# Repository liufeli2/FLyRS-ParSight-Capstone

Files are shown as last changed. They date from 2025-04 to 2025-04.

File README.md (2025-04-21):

# ParSight - FLyRS [ROB498 Capstone]

This repository showcases our work for ROB498, the Robotics Capstone Design course of Engineering Science (Robotics Engineering) at the University of Toronto. Our team is building a fully functional Micro Aerial Vehicle (MAV) that tackles the Sense-Plan-Act paradigm, alongside complete hardware assembly. From brainstorming and prototyping to testing and integration, this project holistically combines our engineering skills to create a cohesive hardware-software system addressing a real-world robotics challenge. In this repository, you'll find design documentation, code, performance evaluations, and final reports—a hands-on technical journey that brings together everything we've learned.

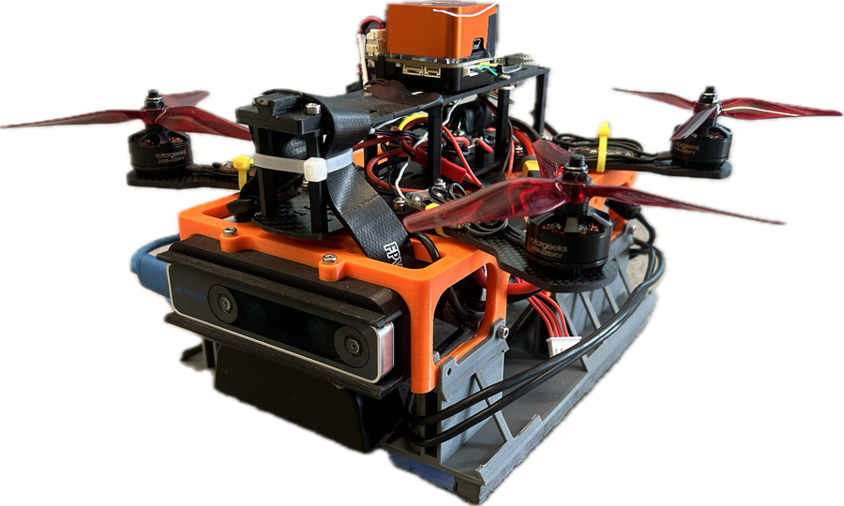
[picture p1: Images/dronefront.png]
ParSight


## Abstract

Golf is an increasingly popular pastime among seniors, offering physical and mental benefits. However, many older golfers report difficulty tracking and locating the ball visually after hitting a shot due to age-related vision decline. Existing ball tracking tools focus on broadcasting graphics and post-game analysis, with no current solutions providing real-time visibility during game play.

ParSight is an autonomous drone-based, real-time golf ball tracking system designed to enhance visibility for senior golfers. The system maintains visual contact with the ball throughout its flight, flies stably, and makes fast, accurate, and robust tracking decisions in real time. To enable fast visual detection using its onboard RGB camera, we use a red golf ball and an HSV-based red filter to enhance red tones while suppressing blue and green channels, followed by added Gaussian blur to reduce image noise. The system uses OpenCV contour detection to identify red regions, scoring them based on size and roundness to select the most likely golf ball candidate. From the selected contour, the center point is extracted and used for tracking, which is performed through Image Based Visual Servoing, where pixel error, the offset between the ball’s position on the screen and the image center, is transformed into a real-world pose correction. ParSight uses a PD controller to determine the drone’s movement, enabling smooth, responsive flight without overshooting. Once the system detects the ball, ParSight autonomously takes off, ascends to tracking height, and locks onto its target ball. When the ball is launched (via a catapult proxy), the drone tracks its flight through rapid acceleration, airtime, bounces, and eventual rolling to a stop. It continues to hover over the ball’s final position, providing constant visual feedback to aid users in locating it.

<p align="left">
  MY580 Demo
  Rviz Demo
</p>

ParSight achieved a detection accuracy of 95% with only a 3% false positive rate. Although processing latency was just 30 ms, the total system reaction time was approximately 350 ms due to hardware constraints such as camera frame rate and resolution. As a result, the maximum positional error reached 75.51 cm, though the system could still reliably recover and reacquire the ball. These results demonstrated that ParSight met the objectives of the MVP: a working prototype that detects and tracks a golf ball quickly and fairly robustly in real-testing conditions.

The design and implementation of ParSight allowed the team to apply concepts from across their undergraduate journey while navigating the real-world challenges of robotics engineering, such as debugging hardware, tuning control systems, integrating computer vision pipelines, recovering from drone crashes, and collaborating effectively as a team throughout the process.

## Team

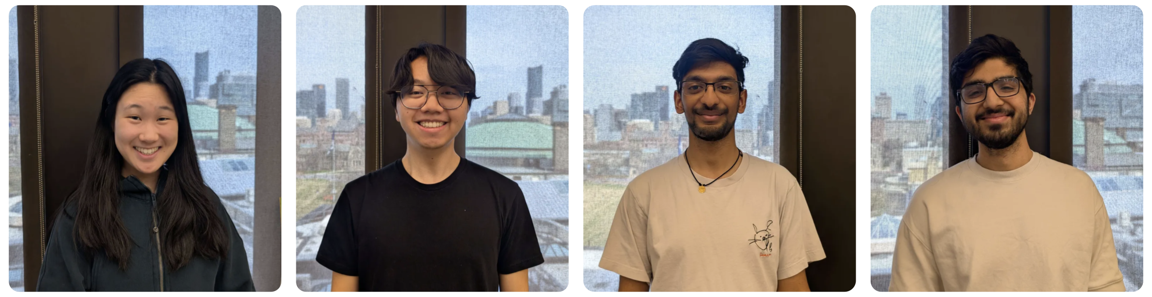
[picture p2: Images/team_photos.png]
Team Photo


We are the FLyRS. From left to right, Felicia Liu, Luke Yang, Rohan Batchu, and Sid Khanna.

## Deliverables

### [Project Proposal](CourseDeliverables/FLyRS_ParSight_Project_Proposal.pdf)
This deliverable served as the foundational step in our project, where we defined the problem, scoped the design, and outlined our approach for solving the golf ball tracking challenge using an unmanned micro aerial vehicle (MAV). The goal was to clearly communicate the design challenge, the motivation behind it, and the proposed solution. We provided a detailed explanation of the design objectives, the critical constraints, and the technical strategy we intend to pursue. This document also sets the stage for the subsequent phases of the project, ensuring alignment with the project's goals and providing a clear framework for evaluation and validation of the final system.

### [Pitch Video](https://youtu.be/EOtyIKrfoxo?si=AKbyNcsjM8_lEWE2)
This video showcases our golf ball tracking drone prototype, demonstrating how it uses computer vision and deep learning to track and locate golf balls in real time. We highlight the key technical features, challenges faced, and how our solution benefits senior golfers and those with mobility issues. The video emphasizes the prototype’s functionality and its potential to improve the golfing experience by providing an intuitive visual aid.

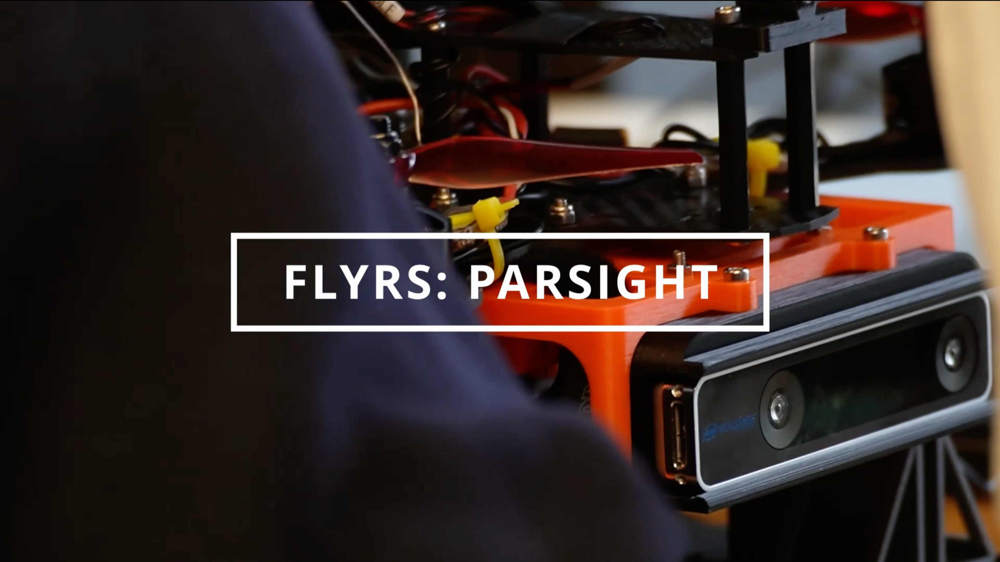
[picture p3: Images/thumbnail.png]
YouTube Video


### [Demo Presentation](CourseDeliverables/FLyRS_ParSight_Demo_Presentation.pdf)
This presentation served as the culmination of our design efforts, where we demonstrated a working prototype that addressed the core problem defined in our proposal. The goal was to showcase the key technical features of our system, explain the design process we followed, and justify the major decisions and trade-offs we made along the way. We aimed to convey the value of our solution, highlight the functionality achieved, and provide a clear understanding of how the prototype fulfilled our main objectives.

### [Final Report](CourseDeliverables/FLyRS_ParSight_Final_Report.pdf)
This report serves as the culmination of our design efforts, where we present a comprehensive overview of our project and the results achieved. The goal is to summarize the design process, highlight key decisions and trade-offs, and demonstrate how the final prototype meets the objectives outlined in our proposal. We aim to clearly communicate the value of our solution, the technical features developed, and the challenges faced throughout the process. Through this report, we provide a detailed understxwanding of the design, its functionality, and how it addresses the core problem.

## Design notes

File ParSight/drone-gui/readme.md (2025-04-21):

# Flight Procedure

## Pre-Flight Checks
- Before launching, complete the following safety and setup steps:
- Ensure all wires are clear, the net is pulled, and the test area is secure.
- Confirm time synchronization between onboard and ground systems.
- Verify vision pose matches local position in RViz.
- Ensure Vicon data is streaming correctly and matches expectations.

## Flight Process
- Launch Camera Node and Detection Node.
- Wait for successful detection of the golf ball in the scene.
- Once confirmed, unkill, arm, and switch to Offboard mode.
- Launch ParSight node to begin visual tracking.
- Wait until drone reaches stable flying height, then begin the test.
- Trigger the catapult once the drone begins active tracking.
- The drone will hover over the ball once it detects the ball has come to rest.
- Land the drone and kill to complete the demo.

## General Troubleshooting
If issues arise during setup or flight:
- Relaunch the MAVROS node.
- Replug drone hardware connections.
- Reboot the Cube flight controller.
- Swap in a fully charged battery.
- Recalibrate sensors if alignment issues persist.

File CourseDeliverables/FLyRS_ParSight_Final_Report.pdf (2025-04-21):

### ROB498: Robotics Capstone Design Team Final Report

# ParSight

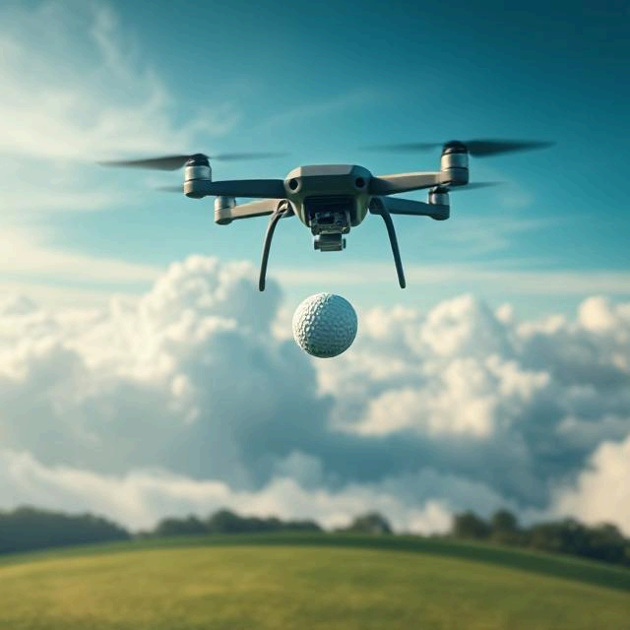
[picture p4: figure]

### Team #1: FLyRS

Felicia Liu (1006950042)
Luke Yang (1006959258)
Rohan Batchu (1006997181)
Siddharth Khanna (1006773341)

## Abstract

Golf is an increasingly popular pastime among seniors, offering physical and mental benefits. However, many older golfers report difficulty tracking and locating the ball visually after hitting a shot due to age-related vision decline. Existing ball tracking tools focus on broadcasting graphics and post-game analysis, with no current solutions providing real-time visibility during game play.

ParSight is an autonomous drone-based, real-time golf ball tracking system designed to enhance visibility for senior golfers. The system maintains visual contact with the ball throughout its flight, flies stably, and makes fast, accurate, and robust tracking decisions in real time. To enable fast visual detection using its onboard RGB camera, we use a red golf ball and an HSV-based red filter to enhance red tones while suppressing blue and green channels, followed by added Gaussian blur to reduce image noise. The system uses OpenCV contour detection to identify red regions, scoring them based on size and roundness to select the most likely golf ball candidate. From the selected contour, the center point is extracted and used for tracking, which is performed through Image Based Visual Servoing, where pixel error, the offset between the ball’s position on the screen and the image center, is transformed into a real-world pose correction. ParSight uses a PD controller to determine the drone’s movement, enabling smooth, responsive flight without overshooting. Once the system detects the ball, ParSight autonomously takes off, ascends to tracking height, and locks onto its target ball. When the ball is launched (via a catapult proxy), the drone tracks its flight through rapid acceleration, airtime, bounces, and eventual rolling to a stop. It continues to hover over the ball’s final position, providing constant visual feedback to aid users in locating it.

ParSight achieved a detection accuracy of 95% with only a 3% false positive rate. Although processing latency was just 30 ms, the total system reaction time was approximately 350 ms due to hardware constraints such as camera frame rate and resolution. As a result, the maximum positional error reached 75.51 cm, though the system could still reliably recover and reacquire the ball. These results demonstrated that ParSight met the objectives of the MVP: a working prototype that detects and tracks a golf ball quickly and fairly robustly in real-testing conditions.

The design and implementation of ParSight allowed the team to apply concepts from across their undergraduate journey while navigating the real-world challenges of robotics engineering, such as debugging hardware, tuning control systems, integrating computer vision pipelines, recovering from drone crashes, and collaborating effectively as a team throughout the process.

All source code, design files, and documentation related to this project can be found in our GitHub repository: https://github.com/liufeli2/FLyRS-ParSight-Capstone.

## Table of Contents

## Design Overview

To help senior golfers with declining vision, we present an autonomous drone-based real-time golf-ball tracking system. Using computer vision and control algorithms, ParSight can track and fly with a golf ball from the tee to its landing location, serving as a larger visual marker. Testing results demonstrate that our prototype reliably tracks a golf ball launched from a mini-catapult, meeting key performance metrics we have defined for a minimum viable product (MVP). With improved hardware, we are confident in our ability to extend this system to track full-speed outdoor shots.

With this solution in mind, we will now explain the significance of the problem it addresses. Golf has become an increasingly popular pastime among seniors, with participation among those aged 65 and older rising by 64% in the past decade and those 50 and above making up 43% of U.S. golfers in 2024 [1]. (https://www.zotero.org/google-docs/?armMck) With the correlation between age and vision decline [2], (https://www.zotero.org/google-docs/?XSq5nM) senior golfers have expressed increasing challenges in tracking and locating the ball after hitting a shot [3][4]. (https://www.zotero.org/google-docs/?Od1ESU) Existing solutions primarily are for performance tracking, video enhancement, or post-game analysis:

- Augmented Reality (AR) Golf Shot Tracers: Enhances video recordings or live broadcasts by overlaying ball trajectories using AR, helping viewers follow the shot more easily. However, these systems are designed for post-processing or broadcast purposes and do not provide real-time tracking for the golfer on the course [5][6]. (https://www.zotero.org/google-docs/?kQMq7y)
- Manually Piloted Drones: A dedicated pilot manually flies a drone to track shots, providing viewers with dynamic camera angles [7][8]. (https://www.zotero.org/google-docs/?h784Wf) However, this setup is unrealistic for everyday golfing, as it requires constant human involvement and disrupts the natural flow of play.
- Follow-Me Drones: Drones equipped with the ability to autonomously track a subject for various sports applications such as skateboarding or biking [9]. (https://www.zotero.org/google-docs/?3dN5NJ) These general solutions do not consider the following small objects travelling in the air at high speeds, such as a golf ball.

By considering the limitations of existing solutions, it is evident there is a gap in the market for a drone that autonomously tracks a golf ball in real-time and helps senior golfers locate their shots.

In developing our solution, the design process was guided by three core values: autonomy, safety, and creativity. First, restoring autonomy to senior golfers is a key element of our value proposition. By offering a larger visual marker to track the ball, our system helps restore the golfing experience seniors used to have without fundamentally changing how the game is played. Second, safety has been a central consideration in our engineering decisions, with an incremental approach that starts with basic implementations and tests and gradually progresses to more integrated evaluations. Finally, creativity shaped our ability to apply both past course knowledge and newly acquired skills in novel ways that have not been explored in this context before. Concerning our design process, the responsibilities and contributions of our team were also divided as follows:

- Felicia: Coded the red detection filter and entire tracking pipeline. Designed and initiated the incremental testing plan, beginning with testing and tuning the detection and tracking systems on a computer before porting them to the drone. Designed the landing gear in CAD.
- Luke: Set up development environment, deployment pipeline, and package management. Created development tools such as graphic user interfaces for easy debugging and automated deployment scripts. Performed data collection and analysis concerning evaluation metrics.
- Rohan: Established the RGB camera vision system. Developed the entire requirements model by researching testing metrics and ideal numbers for the final and MVP design.
- Sid: Developed the YOLO segmentation component before pivoting to the red detection filter, cleaning online datasets, collecting training data, and fine-tuning hyperparameters.

## Background and Related Work

The following section covers all the relevant software frameworks we have used in our final design, explaining how they work, their general use case, and why we have chosen them for our final design solution. The three main components are: HSV colour detection, Image-Based Visual Servoing (IBVS) and Proportional Derivative (PD) Control.

HSV Colour Detection
Colour detection algorithms identify pixels in an image that match a specific colour or colour range [10]. (https://www.zotero.org/google-docs/?RLigol) The HSV colour space is often preferred over RGB because it separates hue, saturation, and value, making colour detection more robust and reliable [11]. (https://www.zotero.org/google-docs/?w3M9QA) The algorithm is particularly well suited in industries like manufacturing, automotive, and food processing where distinguishing between objects based on colour is essential. For example, identifying similar-looking products, inspecting colored adhesives or baked goods, and detecting naturally colourful materials [12]. (https://www.zotero.org/google-docs/?fKOsAu) We selected HSV colour detection for our design because golf balls are typically monochromatic, aligning well with the algorithm’s strengths. Additionally, HSV-based detection is computationally efficient, which is critical for tracking fast-moving objects like a golf ball.

Image-Based Visual Servoing
Image-Based Visual Servoing (IBVS) is a common practice in robotics that utilizes computer vision to provide a closed-loop position control for a robot end-effector. Specifically for mobile robotics, the goal is to control the vehicle’s pose with respect to some landmark [13]. (https://www.zotero.org/google-docs/?xmze43) Within industry, visual servoing has been used for bin picking, packaging, and sorting tasks in a controlled environment [14]. (https://www.zotero.org/google-docs/?c6X8v4) We chose IBVS for our design because it aligns well with our design problem. Specifically, we control the drone’s pose relative to the golf ball, which acts as a visual landmark in the camera frame. Compared to dynamics-based control systems, IBVS also offers a simpler implementation that can take advantage of the drone’s existing integrated setpoint control system.

Proportional Derivative Control
Proportional Derivative (PD) control is a simplified form of the widely used Proportional Integral Derivative (PID) control algorithm. By measuring input data from sensors, the difference between the actual value and the desired setpoint of a system can be calculated and used to adjust the outputs to correct the error [15]. (https://www.zotero.org/google-docs/?UOlTbM) Industry use cases include temperature, power electronics, automatic machines, and automobile control [16]. (https://www.zotero.org/google-docs/?r8EAlR) We chose to use PD control when determining the desired setpoint from the IBVS control output because of its reputable industry performance. We excluded the integral component to prioritize rapid response and effective damping of oscillations, as steady-state accuracy was not a primary concern for our application.

## Design Objectives and Solution Details

In the submitted proposal and during the early stages of the project, the requirements were not as well defined; we have since fleshed out the requirements model through further development. The new requirements are better defined to enable benchmarking and testing of our prototype. In addition to this, feedback from course instructors informed our new scope, which constrained our primary functions to tracking the golf ball, hovering over the golf ball, and being easy to set up and use. One of the goals we removed was the obstacle avoidance due to the limited time frame for prototyping, as well as the limited hardware capabilities of the drone. Some functions were also altered and added to better describe the system’s interfaces and necessary capabilities that were realized during development. Additionally, performance requirements were developed and altered as well as including more finalized specifications.

Our project scope now has 3 main objectives with the following requirement codes:

- MLR-001: Tracking the golf ball from tee-off to rest
- MLR-002: Become a visual marker for the ball at rest
- MLR-003: Ensuring easy setup and use of the drone

These objectives are further broken down into system-level requirements (SLRs) and subsystem requirements, with the following system and subsystems and their codes:

- SLR - System Level Requirements
- IMG - Sensing and Perception
- OBD - Image Processing and Ball Detection
- FLC - Tracking and Path Planning

ParSight employs a requirement classification of three types to use as a framework for aligning design decisions with system performance and operational constraints. The category types are Functional (F), Performance (P), and Constraint (C). The requirement codes follow the syntax: <System>-<Category Type>-<Number>.

As development continued, we found that we were working in three primary areas of imaging, object detection, and actuation. As such, these 3 areas were made into subsystems (IMG, OBD, FLC) that interact with each other and other hardware onboard to create an effective solution as seen in Figure 1. The Localization system is the RealSense/Vicon system that provides real-world position data to send setpoints to the flight controller.

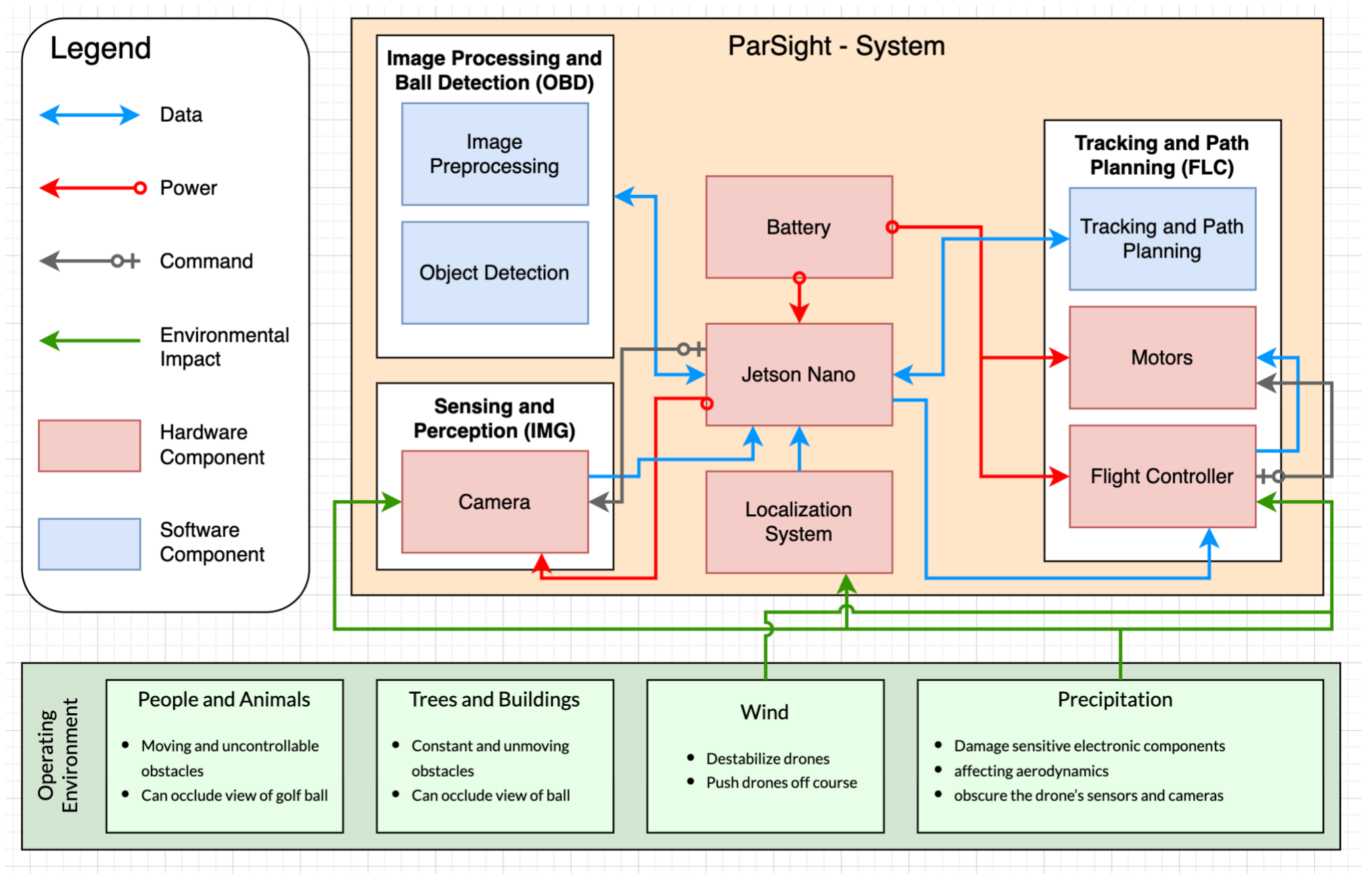
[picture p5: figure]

Figure 1. System Block Diagram showing the connections and interfaces between subsystems, the system,system hardware, and the environment.

Table 1. System Level Requirements(SLRs).
Code | Requirement | Explanation | Parent Req
SLR-P-001 | The processing latency from image to motor commands shall be less than 100 ms | The software pipeline from perception to planning must occur in less than 100ms to track a golf ball with 1 the current hardware specifications | MLR-001
SLR-P-002 | The drone shall be ready to use in under 10 minutes | To reduce technical issues and account for the varying technical skills of users, ease of use is necessary | MLR-003
SLR-F-001 | The drone shall maintain a view of and track the ball throughout flight | To track the golf ball effectively, the camera must have the golf ball in frame at all times | MLR-001
SLR-F-002 | The drone shall have a safe and stable flight when tracking the ball | Drone stability provides smoother transitions for planning and will require less image processing | MLR-001
SLR-F-003 | The drone shall have all the computation onboard | Due to the high possible speed of the golf ball, it is not viable to have a delay in receiving and sending data to a remote computer | MLR-001
SLR-F-004 | The drone shall detect the ball’s position from overhead | Since the ball starts on the ground, tracking from overhead will provide the best possible view of the ball throughout flight | MLR-001
SLR-F-005 | All drone power shall be sourced from the onboard battery | The far distance travelled by the golf ball makes a wired drone unviable | MLR-001
SLR-F-006 | The drone shall maintain a distance such that it will have minimal impact on the golf ball's trajectory | A goal of the project is to minimize the effect of the prototype on the sport of golfing, therefore, the drone must be far enough away such that the lift generated by the drone has minimal effect on the golf ball | MLR-001
SLR-F-007 | The drone shall hover over the golf ball at rest | To provide a larger visual marker for the golf ball location after a swing | MLR-002

Table 2. Subsystem Level Requirements.
Code | Requirement | Explanation | Parent Req
SENSING AND PERCEPTION REQUIREMENTS
IMG-C-001 | The camera shall weigh less than 500 grams | For the drone to be able to fly and react to control inputs, the drone cannot have too much added weight | SLR-F-002
IMG-P-001 | The camera shall provide images at least 20 Hz to the Jetson Nano | For effective tracking, based on the calculations, we require 20 Hz to capture ball motion off of tee-off | SLR-P-001
IMG-P-002 | The camera shall send images with a resolution of at least 480p | Image quality determines the ability of the object detection algorithm to find the ball in the image. A higher quality is generally better, but to find the features in the testing environment, 480p should be enough, as the detection is at a lower distance and fewer overall features [17] (https://www.zotero.org/google-docs/?qsXp1P) | SLR-F-001
IMG-F-001 | The camera shall be securely attached to the drone, facing the ground throughout flight | If the camera is not securely attached, the image and information gathered will not be effective for tracking the golf ball at all times | SLR-F-004
IMG-F-002 | The camera shall operate on power provided by the Jetson Nano | The Jetson provides power for all external devices and sensors, and as such, must be able to run on the provided power | SLR-F-003
IMG-F-003 | The camera shall provide imaging data directly to the Jetson Nano through onboard connections | The Jetson is the onboard computer, and to achieve the objectives, it must receive images from the data | SLR-F-003

1 Based on a camera FOV of 60°, estimated ball speed of 10m/s and a flight height of 2.3m, the distance the ball could travel before being lost from the frame is 1.328m which the ball travels in about 0.1328s. This requires that the pipeline speed be capable of detecting and reacting to this at a rate of at least 7.5 Hz for at least one detection.

IMG-F-004 The Jetson Nano shall provide imaging data to any required programs

The drone and all controls are being run through ROS2, and as such, if the pipeline requires multiple scripts, the images may need to be available in all files when being run all at once

SLR-F-003

IMAGE PROCESSING AND OBJECT DETECTION REQUIREMENTS
OBD-P-001 | The object detection algorithm shall operate at a frequency of at least 20 Hz | For effective tracking and based on the estimated ball speed of the MVP, the minimum required frequency was decided | SLR-P-001
OBD-P-002 | The object detection algorithm shall have a detection true positive rate of at least 90% | Effective tracking requires high recall, so when there are golf balls in the frame, the algorithm can pick out the golf ball and can identify when there is no ball in frame [18] (https://www.zotero.org/google-docs/?XkSWza) | SLR-F-001, SLR-F-002
OBD-P-003 | The object detection algorithm shall have a False Positive Rate of less than 5% | When detecting the golf ball, detecting other objects in the image background would make tracking unviable [19] (https://www.zotero.org/google-docs/?5TV8Uo) | SLR-F-001, SLR-F-002
OBD-P-004 | The object detection algorithm shall have a true positive rate of at least 85% in bright, normal, and low-light conditions | Golf can be played in all sorts of lighting conditions, so ensuring that the performance in varying environments is essential | SLR-F-001, SLR-F-002
OBD-F-001 | The object detection algorithm shall receive imaging data from the imaging system | The object detection algorithm requires images to identify and locate the golf ball | SLR-F-003
OBD-F-002 | The object detection algorithm shall segment the golf ball out of the received image | To achieve project objectives, the object detection algorithm is required to identify and locate golf balls in the image | SLR-F-001

TRACKING AND PATH PLANNING REQUIREMENTS
FLC-P-001 | Using the object detection output, the flight control shall determine drone motion within 20ms | Tracking the estimated ball position in the image and determining the next drone position needs to be done within latency to ensure the ball stays in frame | SLR-P-001
FLC-P-002 | The flight control shall maintain a distance of at most 20 cm from the ball's resting position | The goal of the project is to provide a better location of the ball's final position for the elderly and provide a larger target | SLR-F-007
FLC-P-003 | The flight control shall move with the ball within 150 ms of motion | To reduce latency and ensure that the golf ball is within the camera frame | SLR-F-001
FLC-P-004 | The flight control shall move such that the gold ball is within 10 pixels of the center of the image | To ensure tracking precision throughout flight, a maximum image frame pixel distance must be maintained | SLR-F-004
FLC-P-005 | The drone shall maintain a height of 2.3m above the ball to limit alteration of the golf ball trajectory | To minimize the effects of wind on the trajectory of the ball, a height of 2.3m was chosen to balance Vicon performance and lift force | SLR-F-006
FLC-F-001 | The flight control shall stay within the boundaries of the golf course | To ensure safety for others and the drone, it should remain within a specified region (ie. golf course) | SLR-F-002
FLP-F-002 | The flight control shall have a max speed equal to or greater than the golf ball speed | If the drone is slower than the ball, tracking will not be effective | SLR-F-001, SLR-F-002
FLC-F-003 | The flight controller shall control the drone motors to achieve the motion specified by the FLC | Conversion between the image frame setpoint and the actual drone motion is essential for tracking | SLR-F-001, SLR-F-002
FLC-F-004 | The flight controller shall land the drone if the battery is at 10% or less | This allows for drone safety to be maintained and allows for a controllable landing sequence that will not damage the environment | SLR-F-005

## Design Prototype Overview

This section outlines the implementation of ParSight, including the design and final functionality of the prototype developed. We describe the system architecture and the plan-sense-act paradigm used, including both the hardware and software components that enable our real-time golf ball tracking. We also explain the prototype’s core mechanisms for ball detection, tracking, and flight control to illustrate how the system operates end-to-end. Finally, we discuss the extent to which the current prototype meets the project’s primary objectives, along with the key considerations and modifications needed to scale ParSight for real-world deployment.

Sense-Plan-Act Robotics Paradigm
ParSight follows the Sense-Plan-Act model, a foundational paradigm in robotics that structures a robot's behaviour around three key functions: sensing the environment, planning a response, and acting upon that plan. This model provides a clear and modular way to break down the operations of ParSight’s autonomous golf ball tracking system, helping us understand how each hardware component contributes and integrates into the overall functionality of the system at a high level.

Sensors (Input)
The primary sensor used in ParSight is a downward-facing RGB camera that continuously captures a live video feed of the environment beneath the drone, where we expect to see the golf ball. We selected the NexiGo N660 USB webcam, a practical solution for our vision-based tracking needs [20]. (https://www.zotero.org/google-docs/?QquqQS) This camera can capture video at 30 frames per second, which is suitable for our proof-of-concept tracking tasks. It features a wide-angle 60° field of view, allowing us to observe a broad portion of the scene and track the golf ball effectively from the air. The 1080p Full HD resolution (1920x1080) provides more detail than strictly necessary, but the extra resolution offers flexibility, allowing us to downsample frames to reduce processing load as needed. Its USB-A connectivity simplified hardware integration, as our Jetson experienced issues with the CSI connection port. We mounted the NexiGo camera in a downward-facing orientation, fixed on the drone to ensure that its view was aligned with the drone’s local frame of reference. Once visual input is captured, image processing techniques are used to isolate the location of the red golf ball within the frame, informing the planning system on how the drone should respond.

Figure 2. Sensing Hardware: NexiGo N660 webcam.

Planners (Onboard Computation)
The onboard planning computation is handled by an NVIDIA Jetson Nano, a compact embedded computer with a quad-core ARM Cortex-A57 CPU and a 128-core Maxwell GPU capable of 0.5 TFLOPs (FP16) provided by the course instructors. This processing unit runs the Robot Operating System 2 (ROS2), which manages communication between sensing, planning, and actuation components in a modular and distributed manner. During planning, ParSight processes the image coordinate data to calculate the pixel offset between the detected golf ball and the center of the frame. This offset serves as the input to an Image-Based Visual Servoing (IBVS) algorithm, which determines the directional correction needed to maintain visual alignment. We designed our own Proportional-Derivative (PD) controller external to the built-in Orange Cube + Flight Controller in order to dynamically impose position-based control, which computes the appropriate control signals based on this error, balancing responsiveness with stability. These control outputs are subsequently passed to the actuation system to update the drone’s position in real time.

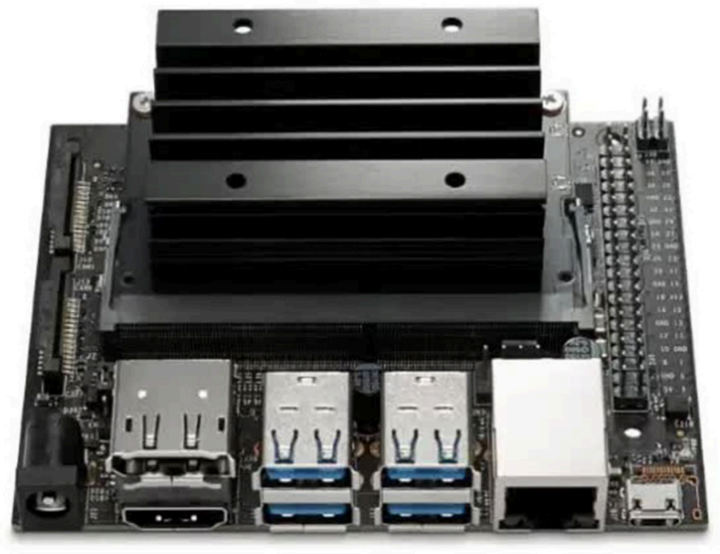
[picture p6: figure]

Figure 3. Planning Hardware: Jetson Nano (IBVS and PD control).

Actuators (Output)
Once a corrective plan is generated, the system translates it into updated flight setpoints that define the drone’s desired position in real time. These setpoints are published through ROS2 on the Jetson Nano and transmitted to the Orange Cube+ flight controller, which interprets them and initiates the appropriate motor commands. The flight controller adjusts the drone’s motion by regulating the Electronic Speed Controllers (ESCs), which in turn drive the brushless motors to produce the necessary thrust and orientation adjustments. ParSight is built on the Minion Mini H-Quad racing drone platform, equipped with 5” three-blade propellers, Spedix ES30 HV30A ESCs, and Rotorgeeks 7075 Series 2206 2350KV brushless motors. The Orange Cube+ flight controller, featuring a 32-bit ARM Cortex M7 processor and integrated IMUs, ensures precise and responsive navigation. This tightly integrated actuation system enables fast, stable flight, allowing ParSight to follow the golf ball’s movement and maintain visual lock throughout its trajectory.

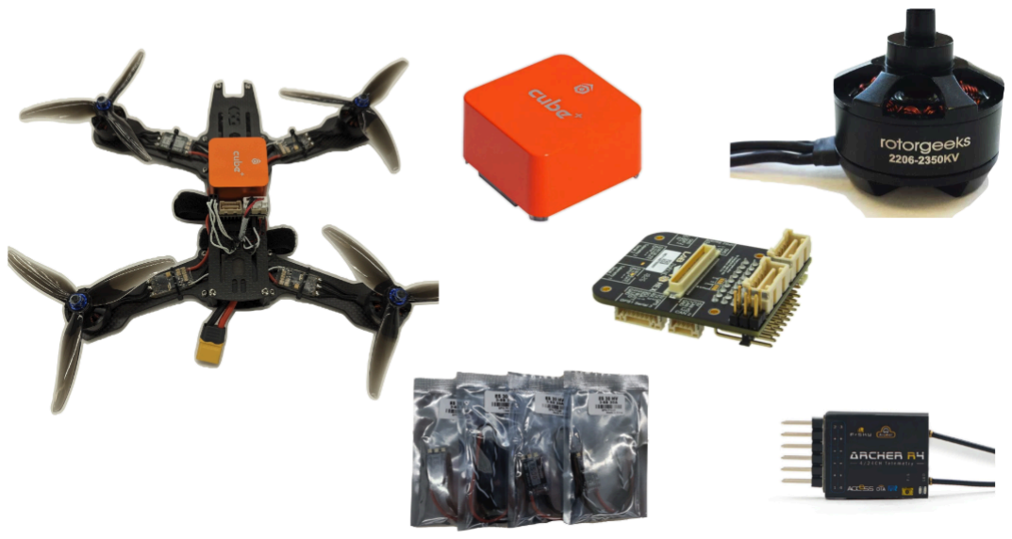
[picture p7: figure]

Figure 4. Flight and Actuation Hardware: Minion Mini H-Quad drone with 5” three-blade propellers, Spedix ES30 HV30A ESCs, Rotorgeeks 2206 2350KV brushless motors, and Orange Cube+ flight controller receiving ROS2 setpoints.

End-to-End Prototype Pipeline
Now we’ll walk through, in more detail, each step of the ParSight prototype pipeline, highlighting how the system operates from input to output (end-to-end). This includes the flow of information from sensing and image capture, through onboard planning and decision-making, all the way to motor-level actuation. Supporting images illustrate each stage of the pipeline, giving a full picture of how the components work together to enable real-time autonomous golf ball tracking.

Sensing & Perception
The first step in ParSight’s end-to-end pipeline is visual sensing. We developed a dedicated ROS 2 node that continuously captures, downsizes, and publishes webcam images, which form the core of ParSight's sensing pipeline. To optimize performance and reduce computational load, each captured frame is resized to 256×256 pixels, balancing image quality with processing efficiency.

The resized frames are then converted into ROS Image messages using CvBridge, ensuring smooth integration with the ROS environment. To maintain a consistent flow of image data, a 30 FPS timer triggers the timer_callback() function, ensuring frames are captured and published at a steady rate. This enables the /camera/image_raw topic to receive real-time image data from the camera.

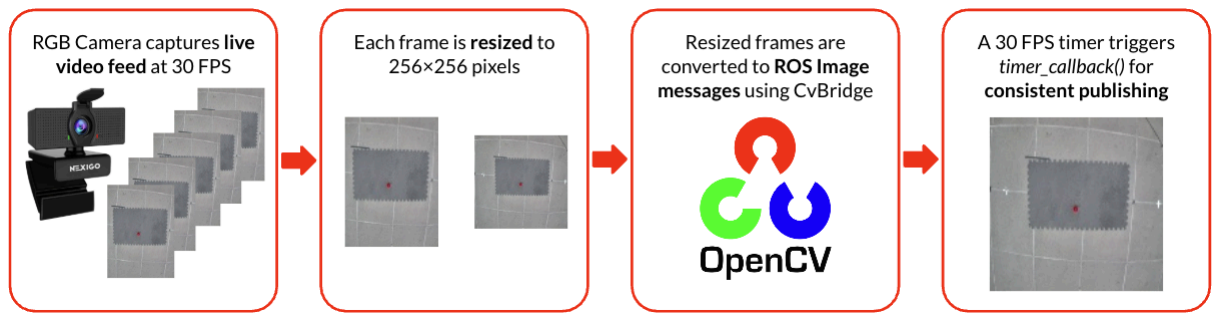
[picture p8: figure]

Figure 5. Image Acquisition Pipeline: Webcam framesresized to 256×256 and published at 30 FPS via ROS2.

Image Processing
The goal of our processing pipeline is to clean up the frames for effective ball detection. We chose a red golf ball for testing due to its strong contrast against the surrounding MY580 environment, making it easier to detect. As a result, the image processing is specifically designed to target the detection of this red ball. The raw camera frames are first received from the /camera/image_raw topic as ROS Image messages and then converted into an OpenCV-compatible format. The frames are subsequently transformed from the standard RGB (Red, Green, Blue) colour space to HSV (Hue, Saturation, Value), as HSV provides better robustness to lighting changes and allows more precise colour segmentation. Next, a mask is created to assist in identifying the red golf ball by applying colour thresholds specifically tuned for the red hue. To minimize interference from other colours, separate masks for green and blue are generated, inverted, and combined with the red mask to focus solely on the ball. A Gaussian blur is then applied to smooth edges and reduce small noise artifacts from the floor texture, enhancing the detection’s stability. This results in the final processed image, which is now clean and ready for ball detection. Although techniques like image undistortion, histogram equalization, and contrast adjustments were considered, they were not implemented in our final prototype. Because our camera performed well without noticeable distortion, even at the edges, and the ball’s circular shape was always clearly detectable, adding these extra processing steps would have slowed down the system, which needed to maintain fast computation times for real-time performance. Hence, we chose a minimal image cleaning approach, prioritizing efficiency and simplicity.

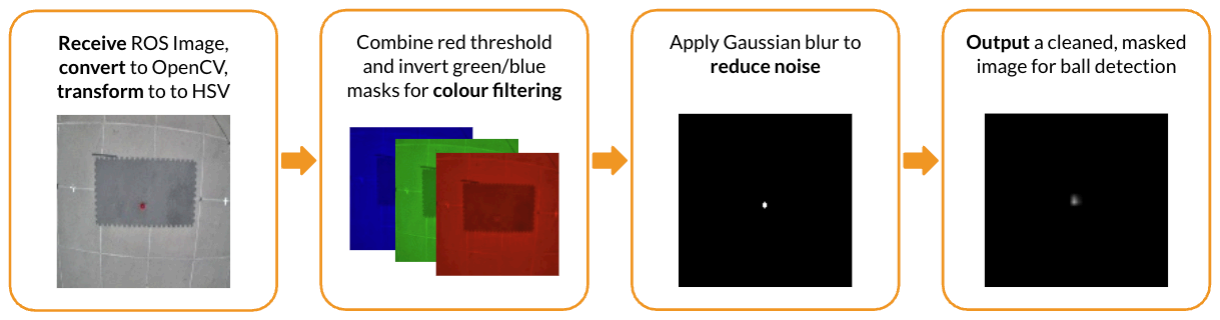
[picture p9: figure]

Figure 6. Image Processing Pipeline: Raw images are converted to HSV, masked for red, cleaned with Gaussian blur, and prepared for ball detection.

Ball Detection
Once the image has been cleaned and processed, we apply contour detection to identify the red golf ball within the frame. Contours are detected in the blurred mask, which helps outline the edges of potential targets. To ensure robustness in selecting the correct contour, we implemented a scoring system that evaluates the size and roundness of each detected contour. Size is calculated as the area of the contour, while roundness is determined by comparing the radius derived from the perimeter to that calculated from the area. A perfect circle will have a roundness score close to 1, while non-circular objects will exhibit greater deviation from 1. By scaling the size by the roundness score, we can determine the most likely candidate for the ball, prioritizing the largest and most round contours. Once the best contour is selected, its center is calculated using image moments. If no contours are found, the system defaults to calculating the center of mass of the entire binary mask as a fallback. This center point, which represents the location of the ball in the frame, is then passed on to the tracking system. If no ball is detected in a given frame, no update is given, and the system assumes that the ball remains stationary. Note in this step that while our system is flexible, allowing us to switch the target ball colour by adjusting a single parameter, the detection method still relies on colour filtering. The ball must be a distinctly different colour from its surroundings and the largest and roundest object of that colour in the environment. While red is ideal for our test environment, white balls, which are more commonly used in real-world outdoor golf settings, would contrast well against green grass, allowing our method to still work.

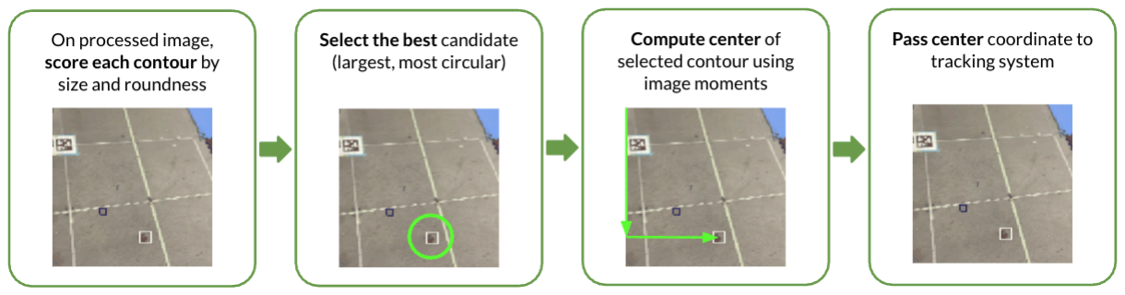
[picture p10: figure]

Figure 7. Ball Detection Pipeline: Contoursin the red mask are scored forsize and roundness; the best match’s center is used for tracking.

Tracking Control
Once the image plane center point of the ball’s position is obtained, the system transitions into the tracking phase. ParSight uses a localized approach, making incremental movements toward the ball at each time step, continuously monitoring the ball’s position and adjusting the drone’s position accordingly, enabling it to follow the target. This is accomplished using an IBVS method, which allows the drone to dynamically respond to the ball’s changing location within the frame. We selected a PD controller for this purpose, as it provides a good balance between responsiveness and stability, allowing fast correction of positional errors while reducing oscillations and overshoot, thereby enabling smoother and more accurate tracking of the golf ball. The IBVS pipeline begins with calculating pixel position errors in the X and Y directions. This is done by determining the difference between the ball’s position in the frame and the frame’s center, giving a pixel error vector. If this vector’s magnitude is within a small threshold (5 pixels), the drone maintains its position and hovers in place. If the error exceeds the threshold, the drone proceeds to compute an error and apply a correction. To translate the pixel offset into a real-world movement, we use a fixed calibration based on the fixed flying height, fixed frame resolution, and the known tile sizes in the world seen in the image frame. Next, PD control is applied. The system calculates the time difference between the current and previous frames to determine the rate of change in error (derivative component). Proportional error is multiplied by Kp gain, and the derivative of the error is multiplied by a Kd gain. The sum of these two components yields the required positional adjustment. These gain values are tuned based on real-world testing, accounting for factors like drone stability, damping, and overshoot. The resulting control values for movement in the X and Y directions are used to update the drone’s setpoint position continuously.

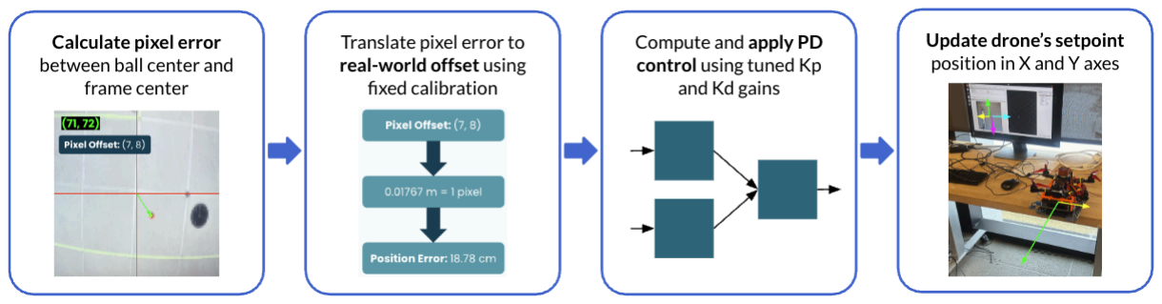
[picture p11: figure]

Figure 8. Tracking Control Pipeline: IBVS with PD control adjusts the drone'ssetpoint based on pixel error between ball and image center.

Actuation
Actuation of the tracking commands is handled through the integration of ROS2 and the drone’s onboard flight control system. The vision pose and computed setpoint positions generated during the tracking process are published via ROS2 on the NVIDIA Jetson Nano. These commands are transmitted to the Minion Mini H-Quad racing drone, where the Orange Cube+ flight controller interprets them and actuates the appropriate motor outputs. The flight controller manages the Electronic Speed Controllers (ESCs) and motors, translating the desired setpoint positions into precise physical movements, allowing the drone to follow the golf ball in real time.

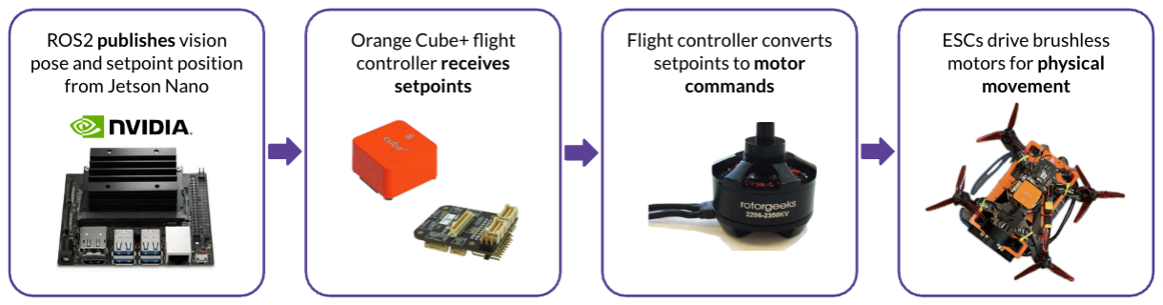
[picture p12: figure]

Figure 9. Actuation Pipeline: ROS2 setpoints guide motor outputs via the Orange Cube+ flight controller to follow the golf ball.

Evaluating Prototype Success Against Objectives
While the later report sections will walk through testing results in detail, it's worth first discussing the higher-level design choices that guided our prototype and how these align with our objectives.

Successes
Our approach prioritized fast and responsive tracking, which is why we selected colour-based detection as it’s lightweight and computationally efficient, which suited our real-time constraints. The amount of image processing we used was also deliberately minimal, enough to sufficiently isolate the red ball effectively while avoiding additional processing steps that would slow the pipeline down without adding much benefit. For tracking, we opted for a reactive PD controller over more complex solutions like Model Predictive Control (MPC). This allowed us to maintain speed and responsiveness without needing to solve optimizations. In terms of detection accuracy, our chosen scoring system, based on both contour size and roundness, added robustness. For example, in initial tests, red tape on the MY580 floor sometimes created false positives because, from a downsampled view, the red tape and the ball appeared similar in size. We observed that their roundness scores were significantly different, allowing us to distinguish the ball reliably.

Challenges
One key limitation we encountered was in tracking high-speed ball motion, particularly during sudden launches. In real-world behaviour, a golf ball doesn't gradually build up speed, it accelerates almost instantaneously from rest to high velocity. This rapid motion poses a significant challenge for our system as the ball often moves so quickly that it exits the image frame before the drone has a chance to react. This delay is primarily due to two factors: the frame rate at which the camera can capture and send images, and the total time required for the rest of the image processing and tracking pipeline to complete its tasks. Another contributing factor is the resolution of the images we use. While higher-resolution frames provide more detail for detecting the ball accurately, they also slow down the processing and the rate at which we can publish raw image updates. This trade-off between precision and speed becomes critical in scenarios involving fast-moving objects. As a result, while our system performs well for moderate-speed tracking and maintains accuracy in controlled environments, further work is needed to improve its responsiveness to rapid motion.

Scaling Toward Real-World Deployment
To transition our ParSight prototype into a real-world system, several upgrades and optimizations would be helpful. A key improvement would be incorporating a higher-frame-rate camera capable of capturing fast-moving objects more reliably. This would reduce the likelihood of missing the golf ball during sudden launches, which currently outpace our system’s ability to react in time. A more powerful onboard hardware, such as the Jetson Orin Nano, would also allow us to process higher resolution frames without compromising speed [21]. (https://www.zotero.org/google-docs/?VAmcdK) Our current pipeline becomes noticeably slower beyond a frame size of 256×256 pixels, limiting our detection precision. More capable computing resources would also allow us to experiment with more intensive techniques such as MPC, enabling the system to anticipate movement rather than solely reacting to it, or consider performing ball detection using YOLO and other deep learning models. Another important area for scaling is more robust false-positive rejection. While our roundness and size-based scoring system has been effective, integrating additional cues like temporal consistency or trajectory validation could reduce misclassification from similarly colored artifacts in complex environments. Together, these enhancements would help narrow the gap between our prototype and a deployable real-time solution suitable for dynamic outdoor or competitive golf scenarios.

## Results and Evaluation

This section presents the testing methodology, performance outcomes and final system evaluation of ParSight. We begin by detailing the structured incremental testing pipeline used to validate individual subsystems before full-system integration, Verification results are then benchmarked against key performance metrics to assess the functionality and responsiveness of the prototype. Furthermore, to assess real-world utility, we conducted validation trials which aim to recreate dynamic golf scenarios, evaluating how well ParSight delivers on its intended purpose. Finally, we reflect on system limitations and outline opportunities for future improvements to enhance performance, robustness, and deployability in outdoor golfing environments.

Testing Pipeline Strategy
To ensure the reliability, safety, and effectiveness of ParSight, we employed a structured, incremental testing pipeline that prioritized subsystem verification before full-system integration. This allowed us to catch potential failures early, tune critical parameters iteratively, and gradually build up to our most complex demonstrations involving autonomous flight and fast-moving targets. Each stage was designed to isolate a specific interaction, be it detection, control, or actuation, so that issues could be addressed without cascading complexity.

Incremental Testing Steps
Our testing strategy began with non-flight validation using laptop-based detection. Once the HSV colour filtering and contour selection pipeline proved robust offline, we transitioned to static onboard testing to verify that real-time image acquisition, ROS topic synchronization, and visualization tools (like RViz) worked as intended. Following this, we introduced actuation logic through simulated motion by manually moving the drone and analyzing how tracking setpoints responded. With confidence in both perception and communication, we introduced autonomous flight for the first time in the “slow hover” tests, where the drone visually locked onto a ball without initiating movement. Subsequent tests introduced incremental motion control, beginning with fixed 1 cm steps, progressing to proportional-only control, and finally stabilizing on a tuned PD controller. These tests helped us measure how precisely the drone could follow the ball, how quickly it could correct errors, and how smooth its response was under different motion profiles. Our final two test stages pushed the limits of system responsiveness. Using an RC car and a mini catapult to simulate fast motion and ball launches, we validated whether ParSight could track a ball through acceleration, bounce, and roll, then hover reliably above its final location. Each test in this pipeline was chosen not just for complexity, but for the specific insights it would offer into detection latency, control response time, and overall robustness.

A full summary of all tests, including test type, control approach, and flight status, is shown in Table 3 below, illustrating the progression from ground-based detection to our final integrated MVP demonstration. The gradual evolution of testing complexity enabled us to debug safely, tune effectively, and build confidence that each part of ParSight was working before deploying the next.

Table 3. Overview of ParSight’stesting pipeline,showing test types, controlstrategies, and flightstatus.

Test Name | Test Type | Control Type | In Flight?
Laptop Detection Test | Detection | - | -
Drone Detection Test | Detection | - | NO
Drone Tracking Test | Tracking | Fixed Step (1 cm) | NO
Drone Detection Slow Movement (S) | Detection | - | YES
Drone Tracking Slow Movement (1cm) | Tracking | Fixed Step (1 cm) | YES
Drone Tracking Slow Movement (P) | Tracking | P Control | YES
Drone Tracking Slow Movement (PD) | Tracking | PD Control | YES
Drone Tracking Fast Movement (PD) | Tracking | PD Control | YES
MVP: Drone Tracking Catapult Launch | Tracking | PD Control | YES

Verification: Metric-Based System Performance
Verification was conducted by comparing system performance against the defined MVP metrics, as outlined in Table 4. This allowed us to assess whether the core subsystems of ParSight functioned correctly and in accordance with the design requirements. All perception-related requirements were met or exceeded. The RGB camera consistently delivered a frame rate of 30 Hz, ensuring real-time image acquisition. The object detection pipeline achieved a true positive rate (TPR) of 95% with a false positive rate (FPR) of only 3%, indicating robust and accurate detection even in cluttered environments and varying lighting conditions. The system maintained a detection rate of 30 Hz with no dropped frames on the Jetson Nano, confirming end-to-end real-time capability. Control-side metrics showed mixed results. The flight control planning speed was measured at 14.1 ms, well under the 20 ms target. However, the reaction speed of 350 ms and tracking precision of 44.2 pixels fell short of the desired thresholds of 150 ms and 40 pixels, respectively. These shortcomings were largely attributed to hardware constraints, specifically the computational limitations of the Jetson Nano, ROS message-passing latency, and the smoothing effects of our PD controller which traded responsiveness for stability. Despite these limitations, the drone consistently responded to motion cues and adjusted its position effectively during all relevant test scenarios, including both our slow-tracking trials and the final MVP demonstration. Processing latency was a key verification metric, and ParSight maintained a steady 30.5 ms, well below the 100 ms limit. This demonstrated that all sensing, detection, and actuation commands could be completed within a single control loop cycle, reinforcing the system’s readiness for real-time use. In total, 8 out of 10 system metrics were successfully met, and the remaining two were close to target. The system exhibited consistent performance and safety throughout flight trials, verifying that the design was both reliable and technically sound.

Table 4. Summary of ParSight’ssystem performance against defined MVP performance requirements, highlighting achieved and unmet benchmarks.

Code/Name | MVP Metric | MVP Result
IMG-P-001: Camera Data Rate | > 20 Hz | 30 Hz
OBD-P-001: Object Detection Rate | > 20 Hz | 30 Hz
OBD-P-002: Object Detection TPR | > 90% | 95%
OBD-P-003: Object Detection FPR | < 5% | 3%
OBD-P-004: Object Detection Robustness | > 85% | 95%
FLC-P-001: Flight Control Planning Speed | < 20 ms | 14.1 ms
FLC-P-002: Flight Control Reaction Speed | < 150 ms | 350 ms
FLC-P-003: Flight Control Tracking Precision | < 40 pixels | 44.2 pixels
FLC-P-004: Flight Control Speed | TRUE | TRUE
SLR-P-001: Drone Processing Latency | < 100 ms | 30.5 ms

Validation: Real-World Tracking Capability
Validation focused on whether ParSight fulfilled its intended purpose, serving as a real-time, autonomous visual aid to help golfers locate their ball after a shot. This was evaluated through a series of progressively more complex flight tests, culminating in a full-system MVP demonstration involving a high-speed catapult launch. In this final test, ParSight successfully detected the golf ball, maintained lock during the ball's flight, and autonomously repositioned itself to hover over the final resting location. The drone remained within 6 cm of the ball’s final position, visually marking its location without requiring user input. The entire process was fully autonomous and repeatable, demonstrating that ParSight could perform its function in dynamic, unstructured environments similar to those encountered on a golf course. The successful execution of this test validated that the system met its overarching user-facing objective. While reaction time and tracking precision were slightly below target, the real-world utility of the system was not compromised. The drone’s visible presence above the ball significantly reduced search time and enabled autonomous tracking without modifying the core golfing experience. As such, ParSight can be considered a validated solution for improving golf ball visibility, particularly for older players facing age-related vision challenges.

Future Work
While ParSight achieved its core design objectives, several areas were identified for further development. One key limitation was the tracking latency and precision, constrained by the compute capacity of the Jetson Nano and ROS communication overhead. Upgrading to a more capable platform, such as the Jetson Orin Nano or an edge device with GPU acceleration, would allow for tighter control loops and smoother real-time responses. In terms of perception, our final implementation relied on HSV-based colour filtering due to its speed and simplicity. While this method enabled fast, lightweight segmentation, it remained sensitive to environmental noise such as red floor markings and lighting changes. One future direction is returning to our earlier YOLO-based segmentation pipeline, which, despite initial performance bottlenecks, offered improved robustness. With upgraded hardware, YOLOv8 or other CNN-based models (ie. MobileNet or EfficientDet) could be run in real time using TensorRT optimization, enabling stronger generalization across ball appearances, surfaces, and lighting conditions. Beyond perception, predictive motion planning could further enhance tracking. Currently, the drone responds reactively to the ball’s position. Incorporating lightweight trajectory estimation or Kalman filtering could help anticipate motion and improve convergence under faster ball movement. We also envision adding dynamic altitude control, enabling the drone to adjust height based on ball speed or vertical arc to improve visibility and mimic a more natural"follow" behaviour. Real-world field deployment, on a driving range or course, remains a critical next step to validate the system's practical effectiveness with senior golfers in outdoor environments. These improvements would help transform ParSight from a proof-of-concept into a deployable assistive drone, offering real-time ball tracking in a wide range of real-world golf scenarios.

## Lessons Learned and Team Reflection

This section concludes with a summary of the challenges encountered throughout the design process, both technical and collaboration-related. From these challenges, we have also reflected on things we would do differently had we completed the design again and provided advice for future teams.

Challenges
Throughout the project, we encountered several challenges that impacted our progress. Hardware errors were a significant issue, large crashes would result in seemingly stochastic errors due to the identifiable source of the problem. For example, the RealSense camera stopped working, which caused pose estimation errors, and damages to the Cube Orange+ flight controller led to discrepancies between vision pose and setpoint positions that could not be resolved. Limited flight time and battery life also posed constraints; course restrictions on available flight times and the batteries provided made it difficult to make necessary adjustments to the colour detection algorithms and the PD controller. Additionally, knowledge sharing within the team was limited. We did not take the time to teach each other about the components we were individually working on, such as how to adjust the colour detection algorithm, tune the PD controller, launch service calls, or fly the drone. As a result, all four members mostly had to be present for any progress to be made. Finally, decision-making was often slow, as all four members needed to agree before proceeding. This was particularly challenging during our limited flight sessions, where quick decisions were crucial to addressing issues with the drone in real time.

Areas for Improvement
There are several areas where our team could improve in future projects. First, we should prioritize simpler solutions early on. We pivoted from YOLO segmentation to HSV colour detection after realizing YOLO was too computationally intensive. In hindsight, starting with HSV filtering would have been more effective, as it was lightweight, simple to implement, and could have served as a proof of concept before progressing to more complex algorithms. Additionally, although our incremental testing plan helped improve the safety and success of our design, we never tested the algorithm in simulation. Recreating the environment and drone in Gazebo would have allowed us to verify that the system’s behaviour met expectations before deployment. Building on this, automated testing, such as unit tests, could have been introduced to ensure that new code pushes didn’t break critical drone functions. For instance, flight tests in simulation could have been triggered automatically with each push to the GitHub repository. Lastly, better documentation would have helped address the knowledge-sharing challenge we faced. By documenting our code throughout the design process, all team members could have better understood each component and contributed more effectively.

Advice for Future Teams
For future teams, there are several key practices that can help streamline development and avoid common pitfalls. First, always maintain fallback code that is known to work and remains unchanged, this allows for quick sanity checks to determine whether issues stem from new code changes or underlying hardware problems. It’s also crucial to ensure that your development environment is properly set up, well-documented, and consistently tracked. This prevents time from being wasted on setup issues and helps onboard new team members more efficiently. Taking the time to go through ROS tutorials can also be incredibly helpful for understanding how workspaces and packages should be structured, as well as learning how to use Git effectively. Finally, don’t overlook DevOps practices, automating deployment processes and building debugging tools like a GUI may seem secondary, but they are invaluable for troubleshooting and maintaining system reliability in the long run. Investing time in these areas early on can significantly improve project outcomes.

## References

[1] “A New Age in Golf?- National Golf Foundation.” Accessed: Apr. 21, 2025. [Online]. Available: https://www.ngf.org/short-game/a-new-age-in-golf/
[2] N. Erdinest, N. London, I. Lavy, Y. Morad, and N. Levinger, “Vision through Healthy Aging Eyes,” Vision, vol. 5, no. 4, p. 46, Sep. 2021, doi: 10.3390/vision5040046.
[3] “How Golf Becomes More Difficult When You Get Older,” Golfshake.com. Accessed: Feb. 10, 2025. [Online]. Available:http://www.golfshake.com/news/view/20587/How_Golf_Becomes_More_Difficult_When_You_Get_Older.html
[4] “Does anyone have issues with eyesight and tracking their golf ball?,” GolfWRX. Accessed: Feb. 10, 2025. [Online]. Available:
https://forums.golfwrx.com/topic/679066-does-anyone-have-issues-with-eyesight-and-tracking-their-golf-ball/
[5] “Shot Tracer,” Shot Tracer. Accessed: Feb. 10, 2025. [Online]. Available: https://www.shottracerapp.com
[6] S. V. G. Contributor, “PGA TOUR Brings Back Live Drone Tracer Tech for FedExCup Playoffs and Presidents Cup,” Sports Video Group. Accessed: Feb. 10, 2025. [Online]. Available: https://www.sportsvideo.org/2024/08/19/pga-tour-brings-back-live-drone-tracer-tech-for-fedexcup-playoffs-and-presidents-cup/
[7] “These insanely fast racing drones capture golf shots as you’ve never seen them,” Golf. Accessed: Feb. 10, 2025. [Online]. Available: https://golf.com/news/racing-drone-golf-shots/
[8] “Drones Follow the Ball on PGA Golf Tour.” Accessed: Feb. 10, 2025. [Online]. Available: https://www.thedroningcompany.com/blog/www.thedroningcompany.com/blog/drones-follow-the-ball-on-p ga-golf-tour
[9] S. French, “The best follow-me drone for tracking sports like skateboarding, biking,” The Drone Girl. Accessed: Feb. 10, 2025. [Online]. Available:
https://www.thedronegirl.com/2020/12/09/best-follow-me-drone/
[10] “Color Detection.” Accessed: Apr. 21, 2025. [Online]. Available: https://www.mathworks.com/help/simulink/supportpkg/android_ref/color-detection.html
[11] “Color Sensing with Computer Vision,” Roboflow Blog. Accessed: Apr. 21, 2025. [Online]. Available: https://blog.roboflow.com/color-sensing-with-computer-vision/
[12] “Color Vision: Is it Better for Robotics?” Accessed: Apr. 21, 2025. [Online]. Available: https://blog.robotiq.com/color-vision-is-it-better-for-robotics
[13] S. Hutchinson, G. D. Hager, and P. I. Corke, “A tutorial on visual servo control,” IEEE Trans. Robot. Autom., vol. 12, no. 5, pp. 651–670, Oct. 1996, doi: 10.1109/70.538972.
[14] “An Overview of Visual Servoing for Robot Manipulators - Technical Articles.” Accessed: Apr. 21, 2025. [Online]. Available:
https://control.com/technical-articles/an-overview-of-visual-servoing-for-robot-manipulators/
[15] “The PID Controller & Theory Explained.” Accessed: Apr. 21, 2025. [Online]. Available: https://www.ni.com/en/shop/labview/pid-theory-explained.html
[16] “Understanding PID Controller: Types, Working, and Applications.” Accessed: Apr. 21, 2025. [Online]. Available: https://multispanindia.com/blog-detail.php/pid-controller-types-working-and-its-application
[17] Y. Hao et al., “Understanding the Impact of Image Quality and Distance of Objects to Object Detection Performance,” Sep. 17, 2022, arXiv: arXiv:2209.08237. doi: 10.48550/arXiv.2209.08237.
[18] M. Breton, “Defence Research and Development Canada Recherche et développement pour la dé fense Canada Overview of two performance metrics for object detection algorithms evaluation Defence Research and Development Canada Reference Document CAN UNCLASSIFIED”, [Online]. Available: https://cradpdf.drdc-rddc.gc.ca/PDFS/unc342/p811371_A1b.pdf
[19] R. Ferrer-Urbina, A. Pardo, W. A. Arrindell, and G. Puddu-Gallardo, “Comparison of false positive and false negative rates of two indices of individual reliable change: Jacobson-Truax and Hageman-Arrindell methods,” Front. Psychol., vol. 14, Jul. 2023, doi: 10.3389/fpsyg.2023.1132128.
[20] “NexiGo 1080P Business Webcam with Software, Dual Microphone & Privacy Cover, NexiGo N660 USB FHD Web Computer Camera, Plug and Play, for Zoom/Skype/Teams/Webex, Laptop MAC PC Desktop : Amazon.ca: Electronics.” Accessed: Apr. 21, 2025. [Online]. Available: https://www.amazon.ca/Upgraded-Microphone-NexiGo-Reduction-Teaching/dp/B08BHX7GYY?th=1
[21] “Jetson Nano vs Jetson Orin Nano 8 GB.” Accessed: Apr. 21, 2025. [Online]. Available: https://technical.city/en/video/Jetson-Orin-Nano-8-GB-vs-Jetson-Nano (https://www.zotero.org/google-docs/?HEO9Mf)

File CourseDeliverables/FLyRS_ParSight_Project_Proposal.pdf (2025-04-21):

### ROB498: Robotics Capstone Design Team Design Proposal

# ParSight


### Team #1: FLyRS

Felicia Liu (1006950042)
Luke Yang (1006959258)
Rohan Batchu (1006997181)
Siddharth Khanna (1006773341)

### Project Overview

Golf is a sport that demands physical strength, accuracy, and experience reading the greens, but it also heavily relies on the player having good vision [1]. (https://www.zotero.org/google-docs/?h9khGp) Skills such as depth perception, hand-eye coordination, reaction time, contrast sensitivity, and fixation are essential for judging distances, aligning shots, and tracking the ball as it soars fast and far [2]. (https://www.zotero.org/google-docs/?xkM5RJ)

This sport has become an increasingly popular pastime among seniors, with participation among those aged 65 and older rising by 64% in the past decade and those 50+ making up 43% of U.S. golfers in 2024. Golf is an ideal sport for this demographic with physical, mental, and social benefits. However, as golfers age, many report increasing challenges in tracking and locating the ball after hitting a shot [3]. (https://www.zotero.org/google-docs/?IkKMRZ) One golfer shared, “I could always follow a golf ball... Now?[...] following a drive? Not a scooby!” [4]. (https://www.zotero.org/google-docs/?kjKJ2V) Another says, “It practically disappears once it reaches near its apex. Sometimes I can't even track it that far.” [5]. (https://www.zotero.org/google-docs/?3KnDgM) These experiences highlight how age-related vision decline adds strain to an already challenging sport.

Tracking the ball is a central part of golf with no existing commercial solutions that aim to reduce the strain of ball-searching for senior golfers. By addressing this challenge, we hope to enhance their enjoyment and help them focus more on the game itself. Thus, our problem statement is as follows: Design a drone that tracks and follows the trajectory of live golf balls in real time, providing the elderly with an assistive visual marker. The proposed drone solution will involve using a camera and computer vision to keep a flying golf ball within its camera’s field of view.

Success will be determined by the drone’s ability to consistently track and follow a golf ball in real time. Key metrics that will be measured are the percentage of time the ball remains in the field of view of the drone, the drone’s movement reaction time, its collision avoidance with the ball and other obstacles, and the final position of the drone relative to the golf ball’s resting location.

### Background

As a group, we share a passion for athletics and value altruism, autonomy, and creativity, believing that drones could bring unique and exciting functionality enhancements to the world of sports. Our problem statement reflects our value of altruism by focusing on a solution that improves seniors’ ability to enjoy golf and promotes inclusivity in the sport. Our proposed design space also aims to give autonomy to golfers by acting solely as a visual aid, allowing players to independently track their shots without altering the traditional golfing experience. This project scope satisfies our team’s value of creativity, as the solution space is novel and exciting, and will require us to utilize both past course knowledge and learn new skills.

There are existing designs that address the opportunity of golf ball tracking. We will evaluate whether they could meet the specific needs of senior golfers and our problem statement.

Augmented Reality (AR) Golf Shot Tracer: Displaying golf ball trajectory using AR has been realized in solutions like TopTracer and Shot Tracer, which are used by ~28,000 PGA professionals worldwide, officially used by the Professional Golfers' Association (PGA) of America [6], (https://www.zotero.org/google-docs/?geQ69w) and accessible to regular golfers through mobile apps [7]. (https://www.zotero.org/google-docs/?p5P845) The PGA tour has also combined AR with drones to provide shot tracking from an aerial perspective [8]. (https://www.zotero.org/google-docs/?5mVpJN) These existing designs primarily enhance the experience for spectators by displaying the golf ball's trajectory on TV or social media. They are not designed for real-time tracking for the golfer and some even allow users to adjust the trajectory if it doesn’t “appear” to their liking [9]. (https://www.zotero.org/google-docs/?rbPtn4) As a result, these solutions do not address our problem statement to provide real-time visual tracking assistance for senior golfers.

Manually Piloted Drones: Another existing solution for real-time golf ball tracking involves a dedicated pilot manually flying a drone to track shots [10] [11]. (https://www.zotero.org/google-docs/?eZQ4RB) Similarly to AR Golf Shot Trackers, this primarily benefits viewers with dynamic camera angles. Having a dedicated pilot also drastically affects the original golfing experience, contradicting our value of autonomy.

Follow-Me Drones: Many commercial drones are equipped with the ability to autonomously track a subject and have been used for various sports applications such as skateboarding or biking [12]. (https://www.zotero.org/google-docs/?TgH50l) These general solutions do not consider following small objects travelling in the air at high speeds, such as a golf ball, and thus, also do not target our problem statement.

By considering the limitations of existing solutions, it is evident there is a gap in the market for a drone that autonomously tracks a golf ball in real-time and helps senior golfers locate their shots.

### Design Objectives

The overall goal of this project is to develop a drone solution that assists senior golfers by tracking golf balls after long tee-offs, providing a visual marker for the ball's location. Given limited time and resources, the project has been scoped to address the identified stakeholder needs in an impactful manner while maintaining feasibility by leveraging our skills in segmentation, tracking, computer vision, and control systems. Ideas such as 3D ball trajectory reconstruction using Gaussian Splatting, and ball retrieval by the drone were excluded from our scope as these features, while valuable, are not critical to achieving the overall goal. The requirements model, shown in Table 1, outlines the key objectives, functions, and constraints of our design space.

Objectives (BE/HAVE) | Functions (DO) | Constraints (SATISFY)
- Serve as Visual Output:
Provide a visible marker
over the ball such that
the location is visible
from a distance.
- Accessibility: Solution is simple and intuitive, and
minimises interaction
and complexity.
- Safe Fly: Predictable and controlled flights.
- Small/Lightweight: Easy
to transport, compact.
- Durable Design: Able to
handle minor impacts
without loss of function.
- Capturing Environment: Use a camera (e.g. RGB-D, RealSense, etc.) to obtain visual information about the environment.
- Segmentation: Accurately detect golf ball in camera video using computer vision.
- Position Tracking: Drone follows ball autonomously by adjusting speed, altitude, and position based on the ball’s flight path to keep the ball in the camera’s frame.
- Landing SpotIdentification: Fly over to the ball once it stops moving, marking its location at rest by hovering overtop.
- Collision Avoidance: Detect and avoid obstacles like trees, water, or sand (or walls).
- A Real-Time Tracker: Provide accurate tracking and fast adjustments.
- Sufficient Battery Life: Capable of continuous flight for 2 hours per full charge to track golf balls throughout a typical 18-hole golf game minimising battery changes required [13]. (https://www.zotero.org/google-docs/?ISadv2)
- Minimum Max Speed: Must fly at ~150 MPH to keep up with golf balls, which are hit at speeds between 111 mph and 147 mph on average [14]. (https://www.zotero.org/google-docs/?rD5WCf)
- Image Segmentation Accuracy: The algorithm must achieve an IoU score of at least 0.75 to accurately identify the golf ball. [15]. (https://www.zotero.org/google-docs/?zd4yUu)
- Image Processing/Capture Rate: Software must process images at 10 Hz* and take images at 20 Hz* for real-time tracking of the golf ball. *Currently educated guesses, to be revised.
- Robot Footprint: Avoid obstacles within a 2-meter radius with 100% success.
Table 1. Requirements Model with functions, objectives, and constraints.

The critical design parameters for effective ball tracking include the camera's imaging rate, processing speed, and field of view. The camera must capture images quickly enough to track the ball's fast movement, while the processing speed must be able to handle these images in real-time. A sufficient field of view ensures the ball stays within the frame for continuous tracking. Balancing these factors is essential for optimal performance.

While the design parameters are essential, considering environmental and societal concerns is also important. Noise pollution could disturb other golfers, and drone malfunctions may result in debris and litter or disrupt local wildlife. Privacy issues could arise from unintended footage capture, and the cost of the technology could create accessibility barriers for some users. It will be important to have awareness of and discuss these concerns to create a responsible solution.

### Design Strategy

Design Prototype Demonstration Plan: We aim to develop a drone that autonomously tracks a golf ball in flight, keeps it within the camera's frame of view, and hovers over the stationary ball once it lands, providing a visual marker for the golfer to easily locate the ball, as shown in Figure 1. To demonstrate this functionality, we will begin testing by gently lobbing a golf ball, ensuring the drone maintains visual tracking, moves closer as needed, and hovers over the ball. This controlled setup allows us to refine detection, tracking, and flight controls before progressing to faster throws and outdoor tests.

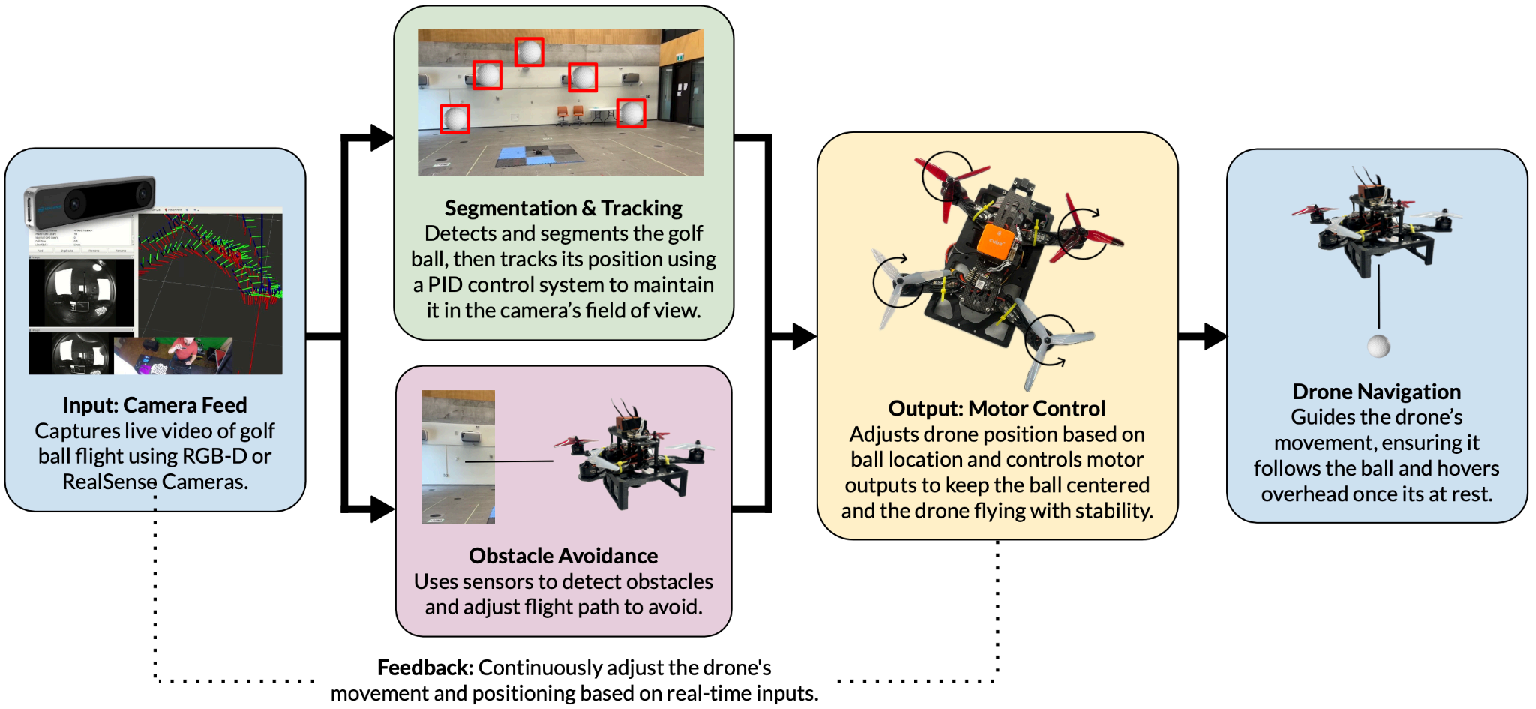
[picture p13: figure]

Figure 1. Block Diagram conveys how different design components and stages will interact.

To address our design problem, we will take a sequential and iterative approach, gradually building functionality on our drone to track golf ball flights in real-time. Incremental steps are given below.

Segmentation and Tracking in Software: Firstly, we will capture videos of moving golf balls in MY580 to create a dataset for segmentation training. We aim to explore several segmentation networks, including U-Net, YOLO, and DeepLabv3+ with various backbone architectures such as VGG-16, Resnet-50, and MobileNet to train a model that efficiently and accurately segments the moving golf ball in the captured video frames [15]. (https://www.zotero.org/google-docs/?1eachK) We will verify that the segmentation is robust and capable of handling variations in depth, trajectory, and colour deviations. By testing the model in software initially to ensure accurate segmentation, this will ensure that the drone can later maintain the ball in frame when the model runs on the Jetson Nano in real-time.

Visual Servoing (VS) and Drone Control: We plan to develop an Image Based (IBVS) or Position Based (PBVS) control loop where the drone uses the bounding box or image plane features to keep the ball centred in the RGB-D or RealSense camera’s frame of view. This will likely involve a PID control system to adjust motor outputs based on deviations from the ball's trajectory.

Integration for Basic Tracking: Next, we will integrate the segmentation and control system to create basic tracking capabilities. This phase will involve testing the drone's ability to follow slower golf ball throws, starting with rolled balls and progressing to tracking balls in flight from a distance. The drone should hover overhead and follow the ball's XY trajectory until the ball comes to rest.

Obstacle Avoidance: In parallel, we will incorporate obstacle avoidance to prevent the drone from encountering hazards such as trees, water, or sand. This will likely involve using visual sensors like the RGB-D camera to construct point clouds which will be converted to a 3D occupancy grid with packages such as OctoMap [16]. (https://www.zotero.org/google-docs/?1ETLye) Algorithms such as Trajectory Rollout can then be used to locally avoid obstacles while still being able to follow the ball. Testing will be done with obstacles in MY580 to proxy the real world.

Anticipated Tradeoffs: Due to the high speed of the golf ball, the drone’s software must process images quickly to track it effectively. However, high-accuracy image segmentation models often have slower runtimes. As a result, we anticipate needing to tradeoff segmentation accuracy with processing speed, sacrificing some precision to ensure real-time tracking performance.

Mitigation Strategy: To minimize integration issues, we will establish clear coding conventions and test subsystems independently before combining them. For debugging, the drone will transmit segmented images to a laptop, allowing us to verify segmentation accuracy in real time. If we notice inconsistent or inaccurate segmentations, we can refine the dataset, apply augmentation, or explore other pre-trained models to improve performance. If the RGB-D camera or obstacle avoidance systems fall short, we will consider adding Time-Of-Flight sensors and pre-define obstacles in the testing environment. If hardware limitations or control system challenges occur, we will simplify ball-tracking scenarios (e.g. slower trajectories) and rescope to focus on core features, ensuring the drone can track and mark the ball’s final location.

### Verification, Validation, and Evaluation

A combination of verification and validation assessments will ensure that technical components operate safely and as intended while meeting the design goals and stakeholder requirements. Verification ensures the functional and mathematical correctness of our system using systematic testing. Validation ensures the system meets user needs by assessing tracking accuracy, reaction time, stability, obstacle avoidance, and final positioning. These are presented below in Table 2.

Verification | Validation
- Simulations: Visually verify the flight
stability, visual tracking, and control
algorithms using Gazebo and Rviz.
- Unit Testing: Verify the functionality of individual subsystems, including computer vision, flight control, and object tracking (expected 90% detection accuracy).
- Integration test: All subsystems interact with others without errors.
- Final Position: The drone’s final position should deviate no more than 1 meter from the ball’s final resting position
- Obstacle Avoidance: Achieve a 100% success rate. No collisions.
- Tracking Accuracy: Targeting an average IoU of at least 0.75 to ensure high overlap between detected and actual ball positions.
- Response Time: Drone’s response should be no slower than ~0.1 seconds.
- End-to-End Test: Ensure all subsystems work together, with the drone autonomously detecting, tracking, and following the golf ball, achieving fewer than 25% tracking failures. The PID controller will be fine-tuned for minimal tracking error and an average response time under 0.1 seconds.
Table 2. Verification and Validation Metrics and Justification.

One factor to consider when evaluating system accuracy is the method for obtaining the ground truth ball position. A possible approach is triangulation, where multiple cameras record from different locations to calculate the ground truth. This method offers high accuracy but may still have discrepancies as an aggregated value. Additionally, since verification and validation occur indoors, factors like lighting variations and occlusions may still impact tracking performance. Despite these challenges, the system is expected to perform reliably within acceptable tolerances.

The requirements model and design strategy we've outlined will guide our efforts toward successfully achieving our goals, and we're hopeful we’ll be able to achieve them.

### References

[1] D. S. Norris, “Optimizing Vision for Golfers.” Accessed: Feb. 10, 2025. [Online]. Available: https://downtownvisioncare.com/optimizing-vision-for-golfers/
[2] russ, “Vision for Golf,” Optometrists.org. Accessed: Feb. 10, 2025. [Online]. Available: https://www.optometrists.org/general-practice-optometry/guide-to-sports-vision/what-is-sports-vision/vision-for-golf/
[3] N. Erdinest, N. London, I. Lavy, Y. Morad, and N. Levinger, “Vision through Healthy Aging Eyes,” Vision, vol. 5, no. 4, p. 46, Sep. 2021, doi: 10.3390/vision5040046.
[4] “How Golf Becomes More Difficult When You Get Older,” Golfshake.com. Accessed: Feb. 10, 2025. [Online]. Available: http://www.golfshake.com/news/view/20587/How_Golf_Becomes_More_Difficult_When_You_Get_Older.html
[5] “Does anyone have issues with eyesight and tracking their golf ball?,” GolfWRX. Accessed: Feb. 10, 2025. [Online]. Available: https://forums.golfwrx.com/topic/679066-does-anyone-have-issues-with-eyesight-and-tracking-their-golf-ball/
[6] “About,” Toptracer. Accessed: Feb. 10, 2025. [Online]. Available: https://toptracer.com/about/
[7] “Shot Tracer,” Shot Tracer. Accessed: Feb. 10, 2025. [Online]. Available: https://www.shottracerapp.com
[8] S. V. G. Contributor, “PGA TOUR Brings Back Live Drone Tracer Tech for FedExCup Playoffs and Presidents Cup,” Sports Video Group. Accessed: Feb. 10, 2025. [Online]. Available: https://www.sportsvideo.org/2024/08/19/pga-tour-brings-back-live-drone-tracer-tech-for-fedexcup-playoffs-and-presidents-cup/
[9] D. J. Watts, “What’s The Point Of A Shot Tracer If It Can Be Faked?,” WAX Golf. Accessed: Feb. 10, 2025. [Online]. Available: https://waxgolf.com/2022/03/27/whats-the-point-of-a-shot-tracer-if-it-can-be-faked/[10]“These insanely fast racing drones capture golf shots as you’ve never seen them,” Golf. Accessed: Feb. 10, 2025. [Online]. Available: https://golf.com/news/racing-drone-golf-shots/[11]“Drones Follow the Ball on PGA Golf Tour.” Accessed: Feb. 10, 2025. [Online]. Available: https://www.thedroningcompany.com/blog/www.thedroningcompany.com/blog/drones-follo w-the-ball-on-pga-golf-tour
[12]S. French, “The best follow-me drone for tracking sports like skateboarding, biking,” The Drone Girl. Accessed: Feb. 10, 2025. [Online]. Available: https://www.thedronegirl.com/2020/12/09/best-follow-me-drone/
[13]“How Long Does It Take to Play 18 Holes in Golf?” Accessed: Feb. 10, 2025. [Online]. Available: https://www.curated.com/journal/291001/how-long-does-it-take-to-play-18-holes-in-golf [14]“What Is Ball Speed in Golf: Breaking Down the Data,” Foresight Sports. Accessed: Feb. 10, 2025. [Online]. Available: https://www.foresightsports.com/blogs/golf-tips/what-ball-speed-golf-breaking-down-data [15]I. Ahmed, M. Ahmad, and G. Jeon, “A real-time efficient object segmentation system based on U-Net using aerial drone images,” J. Real-Time Image Process., vol. 18, no. 5, pp. 1745–1758, Oct. 2021, doi: 10.1007/s11554-021-01166-z.
[16]A. Hornung, K. M. Wurm, M. Bennewitz, C. Stachniss, and W. Burgard, “OctoMap: an efficient probabilistic 3D mapping framework based on octrees,” Auton. Robots, vol. 34, no. 3, pp. 189–206, Apr. 2013, doi: 10.1007/s10514-012-9321-0. (https://www.zotero.org/google-docs/?hhUtO4)

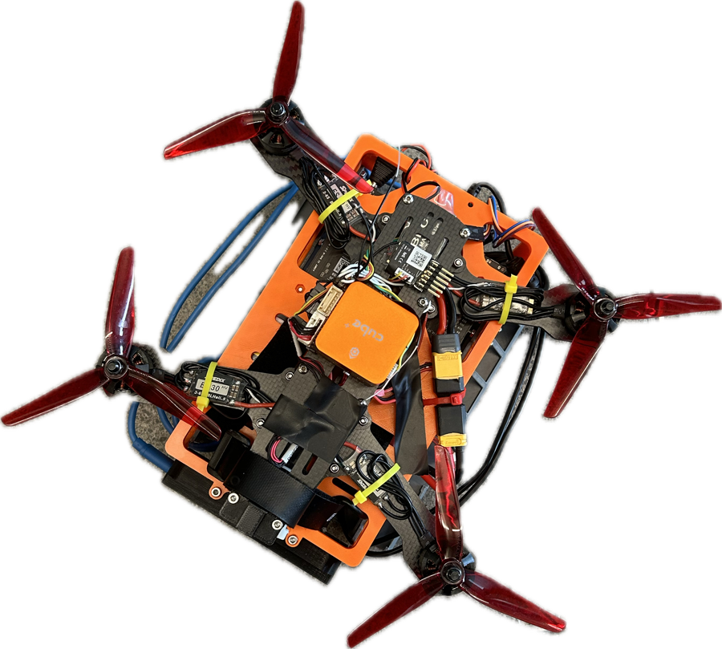
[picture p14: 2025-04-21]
Images/drone.png

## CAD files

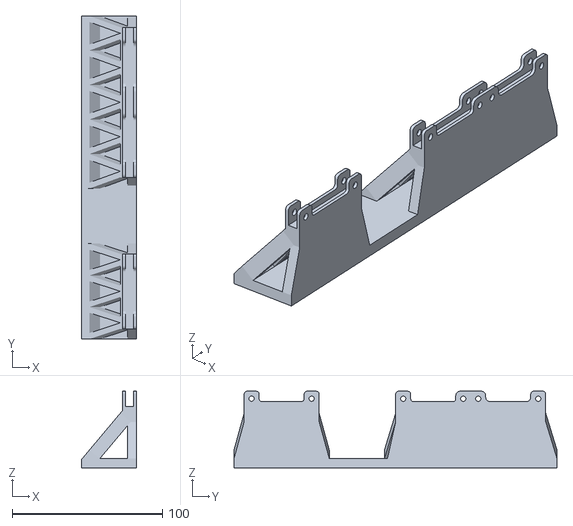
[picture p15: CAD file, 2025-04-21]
CAD/right_side_legs.stl
36.3 x 215.2 x 51.1

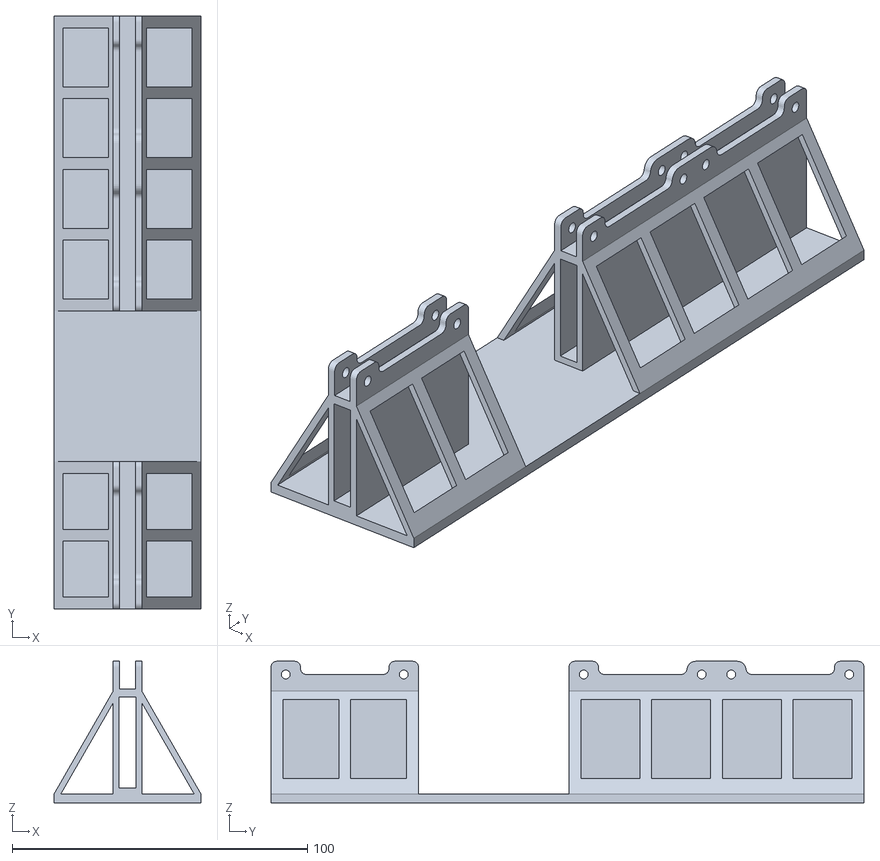
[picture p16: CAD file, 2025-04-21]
CAD/sturdy_legs.stl
49.8 x 201.0 x 48.0

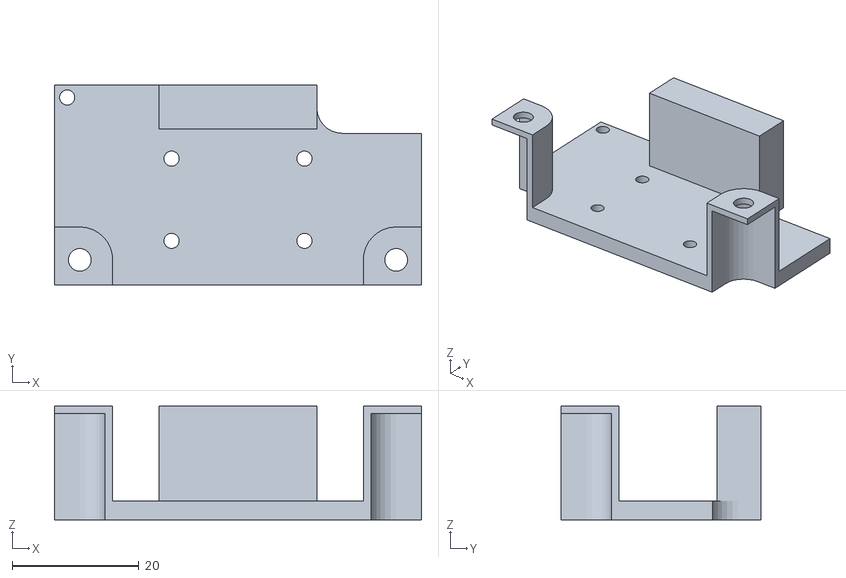
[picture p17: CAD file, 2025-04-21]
CAD/camera_mount.stl
58.0 x 31.7 x 18.0

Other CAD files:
CAD/left_side_legs.stl
